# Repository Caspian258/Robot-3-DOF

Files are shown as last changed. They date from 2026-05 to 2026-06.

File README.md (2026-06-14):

# Robot 3-DOF

Sistema de control para un brazo robótico RRR de 3 grados de libertad, basado en ESP32 con control PD e interfaz gráfica en MATLAB.

## Inicio rápido

> **Requisito previo:** tener [Python 3.8+](https://www.python.org/downloads/) instalado.

**Linux / macOS**
```bash
bash tools/setup.sh
```

**Windows**
```
tools\setup.bat
```

El script instala PlatformIO y pyserial, y pre-descarga la plataforma ESP32 (~200 MB). Después solo necesitas conectar el ESP32 y ejecutar `cd firmware && pio run --target upload`.

---

## Requisitos

| Componente | Versión mínima | Notas |
|---|---|---|
| MATLAB | R2021a | `serialportlist()` requiere R2021a o superior |
| Python | 3.8+ | Solo para el bridge serial en Linux |
| PlatformIO CLI | cualquiera | Recomendado para flashear el firmware |
| Arduino IDE | 2.x | Alternativa a PlatformIO |

---

## Archivos del proyecto

| Archivo | Descripción |
|---|---|
| `firmware/robot3dof_firmware.ino` | Firmware para ESP32 — control PD de 3 motores DC con encoders |
| `firmware/platformio.ini` | Configuración de PlatformIO para ESP32 |
| `matlab/RobotController.m` | GUI de MATLAB — visualización 3D, cinemática inversa, telemetría en tiempo real |
| `tools/robot_serial_bridge.py` | Bridge serial en Python — evita conflictos de lock files en Linux |
| `tools/setup.sh` / `tools/setup.bat` | Scripts de instalación automática (Linux/macOS y Windows) |
| `requirements.txt` | Dependencias Python para el bridge |

---

## Hardware

- **Microcontrolador:** ESP32 DevKit
- **Motores:** 3× JGA25-370 DC con encoder magnético (6 cables)
- **Driver:** L298N (puente H por motor)

### Pines ESP32

| Motor | ENC_A | ENC_B | IN1 | IN2 | ENA |
|---|---|---|---|---|---|
| M1 (Base / yaw) | 18 | 19 | 21 | 22 | 23 |
| M2 (Hombro / pitch) | 32 | 33 | 25 | 26 | 27 |
| M3 (Codo / pitch) | 4 | 5 | 13 | 14 | 16 |

### Parámetros del robot

| Eslabón | Longitud |
|---|---|
| L1 (columna/base) | 100 mm |
| L2 (hombro) | 205 mm |
| L3 (codo/antebrazo) | 165.69 mm |

---

## Setup — Firmware ESP32

### Opción A: PlatformIO (recomendado)

El repositorio ya incluye `firmware/platformio.ini` configurado para la placa `esp32dev`.

1. Instalar Python 3.8+ si no lo tienes.
2. Instalar PlatformIO CLI:
   ```bash
   pip install platformio
   ```
3. Compilar y flashear:
   ```bash
   cd firmware
   pio run --target upload
   ```
   PlatformIO descarga automáticamente el toolchain de Espressif la primera vez.

4. Monitor serial (opcional):
   ```bash
   pio device monitor --baud 115200
   ```

### Opción B: Arduino IDE 2.x

1. Descargar e instalar [Arduino IDE 2.x](https://www.arduino.cc/en/software).
2. Abrir **File → Preferences** y agregar esta URL en "Additional boards manager URLs":
   ```
   https://raw.githubusercontent.com/espressif/arduino-esp32/gh-pages/package_esp32_index.json
   ```
3. Ir a **Tools → Board → Boards Manager**, buscar `esp32` e instalar el paquete de Espressif.
4. Seleccionar **Tools → Board → ESP32 Arduino → ESP32 Dev Module**.
5. Abrir `firmware/robot3dof_firmware.ino`, compilar y subir.

> El firmware no requiere librerías externas — solo el core Arduino para ESP32.

---

## Setup — GUI MATLAB

**Requisito:** MATLAB R2021a o superior (sin toolboxes adicionales).

1. Conectar el ESP32 por USB.
2. Abrir MATLAB, navegar a la carpeta `matlab/` y ejecutar:
   ```matlab
   RobotController
   ```
3. Seleccionar el puerto serial en el desplegable (ej. `COM3` en Windows, `/dev/ttyUSB0` en Linux).
4. Presionar **CONECTAR**.
5. Introducir coordenadas X, Y, Z en mm y presionar **EJECUTAR TRAYECTORIA**.

---

## Setup — Bridge Python (solo Linux, opcional)

Útil cuando MATLAB no puede adquirir el lock del puerto serial en Linux.

```bash
pip install -r requirements.txt
python tools/robot_serial_bridge.py
```

---

## Protocolo Serial (115200 baud)

### MATLAB → ESP32

| Comando | Descripción |
|---|---|
| `T,deg1,deg2,deg3` | Nuevo setpoint en grados para los 3 motores |
| `K1,Kp,Kd` | Ganancias PD del motor 1 |
| `K2,Kp,Kd` | Ganancias PD del motor 2 |
| `K3,Kp,Kd` | Ganancias PD del motor 3 |
| `DB,d1,d2,d3` | Zona muerta por motor (grados) |
| `ZERO` | Resetear encoders y setpoints a cero |
| `DISARM` | Desactivar control, motores en freno |
| `FREE` | Soltar corriente (motores libres) |

### ESP32 → MATLAB

| Respuesta | Descripción |
|---|---|
| `D,q1,q2,q3,e1,e2,e3,pwm1,pwm2,pwm3` | Telemetría: posición actual, error y PWM de los 3 motores |
| `READY` | ESP32 listo tras el boot |
| `ZEROED` | Confirmación de reset de encoders |
| `DISARMED` | Confirmación de desactivación |
| `FREE` | Confirmación de motores libres |

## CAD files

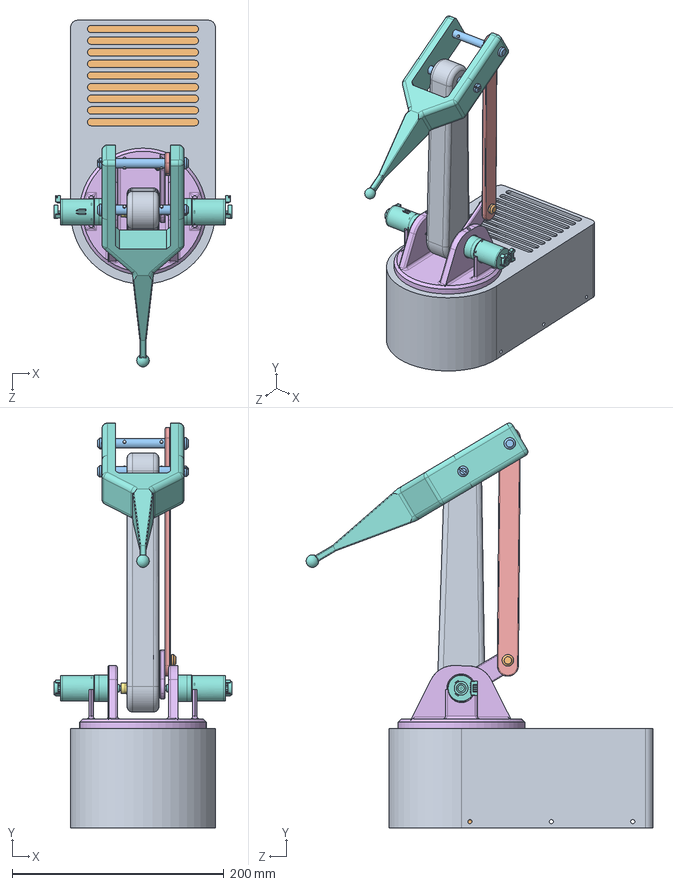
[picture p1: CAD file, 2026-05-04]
CAD/3DOFROBOT.SLDASM
167.8 x 382.8 x 327.8 mm
Arm1
Arm2
PIN3
Base
RotatoryBase
GearBaseRod
GearBaseServo
BoxBase
BoxTop
GM25-370 x 3
5mmFlangeCoupler x 2
ESLABON 2
ESLABON
BALERO
EJE LARGO x 2
Eje corto
Segurito x 4

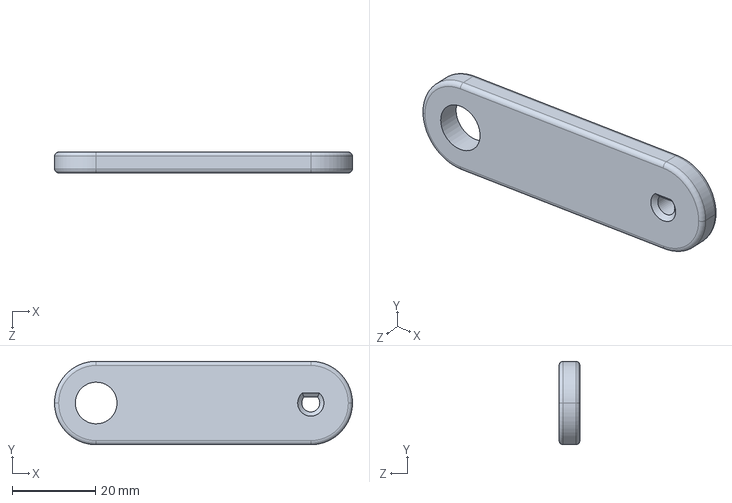
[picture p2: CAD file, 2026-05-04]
CAD/ESLABON 2.SLDPRT
71.5 x 20.0 x 5.00 mm

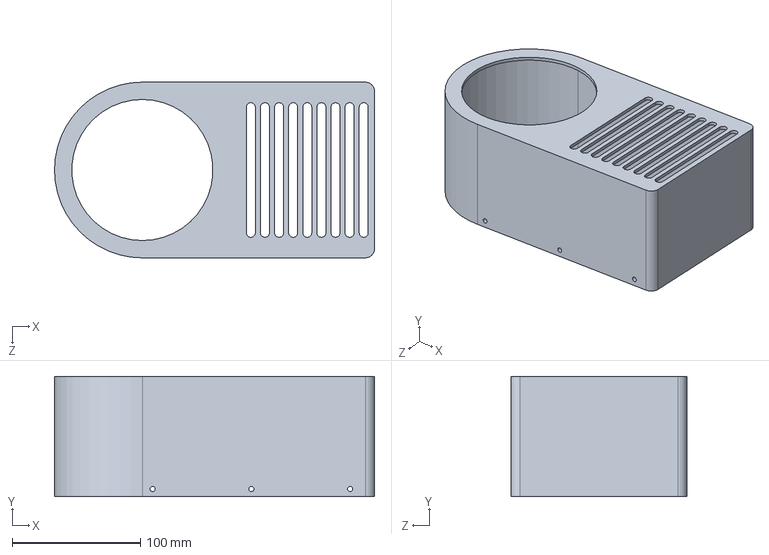
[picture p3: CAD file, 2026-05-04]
CAD/BoxTop.SLDPRT
249.5 x 93.9 x 137.0 mm

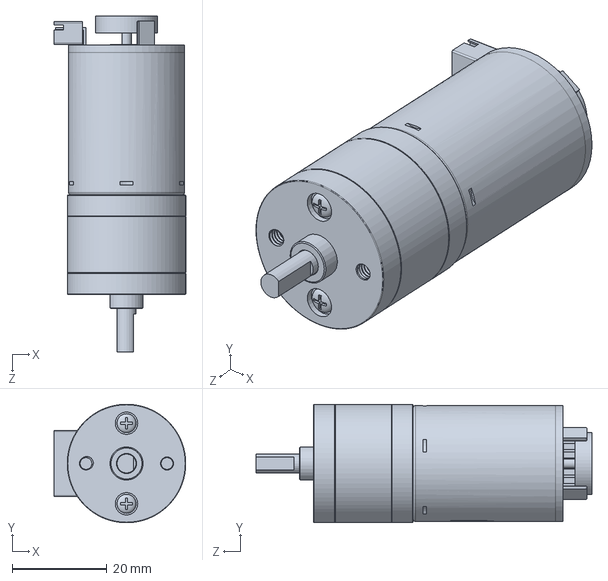
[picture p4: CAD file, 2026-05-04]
CAD/GM25-370.SLDPRT
27.8 x 25.0 x 70.9 mm

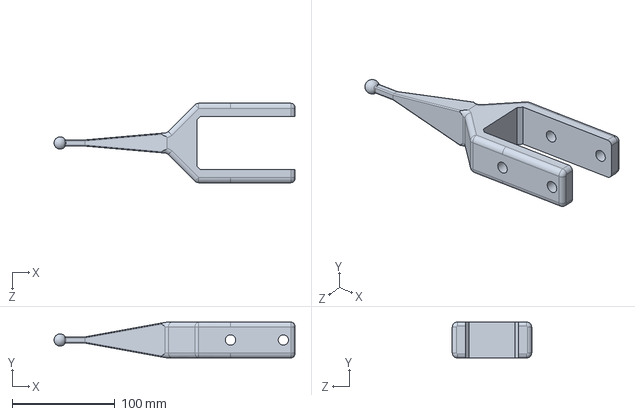
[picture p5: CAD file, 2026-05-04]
CAD/Arm2.SLDPRT
234.5 x 35.0 x 77.4 mm

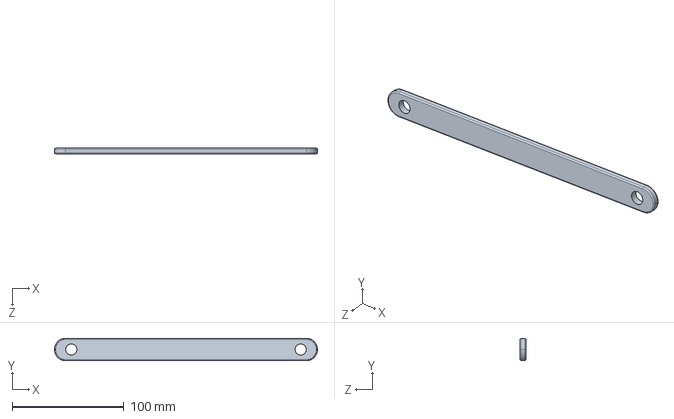
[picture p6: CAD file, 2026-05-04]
CAD/ESLABON.SLDPRT
235.0 x 20.0 x 5.00 mm

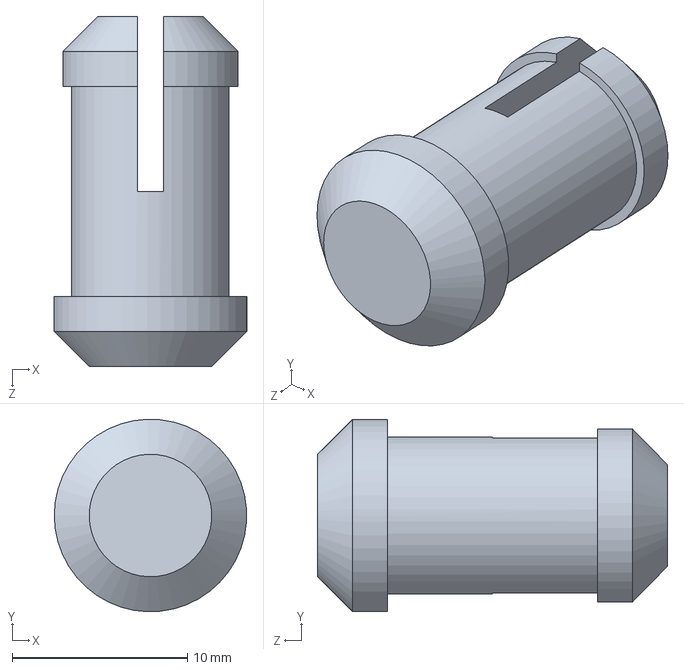
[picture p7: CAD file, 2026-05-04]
CAD/Eje corto.SLDPRT
11.0 x 11.0 x 20.0 mm

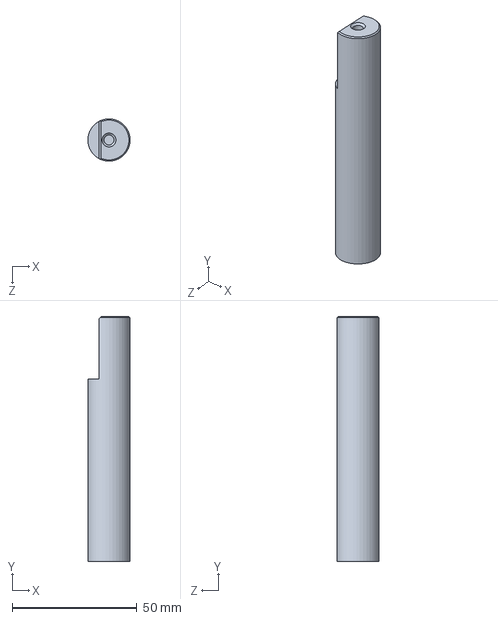
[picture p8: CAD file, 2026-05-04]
CAD/PIN3.SLDPRT
16.9 x 98.3 x 17.0 mm

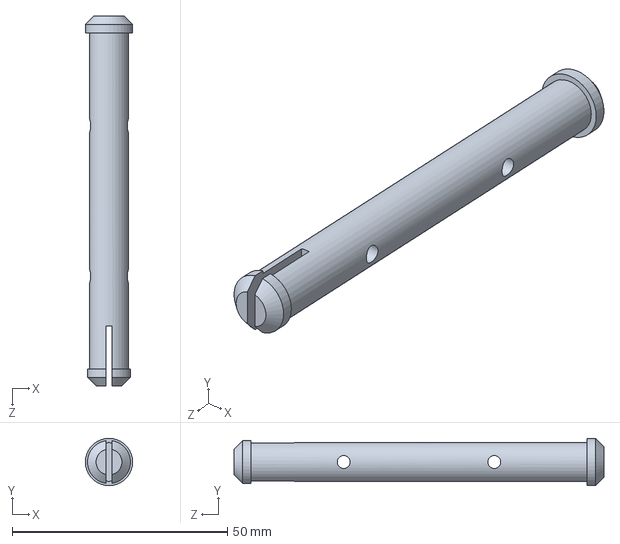
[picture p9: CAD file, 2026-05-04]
CAD/EJE LARGO.SLDPRT
11.0 x 11.0 x 86.0 mm

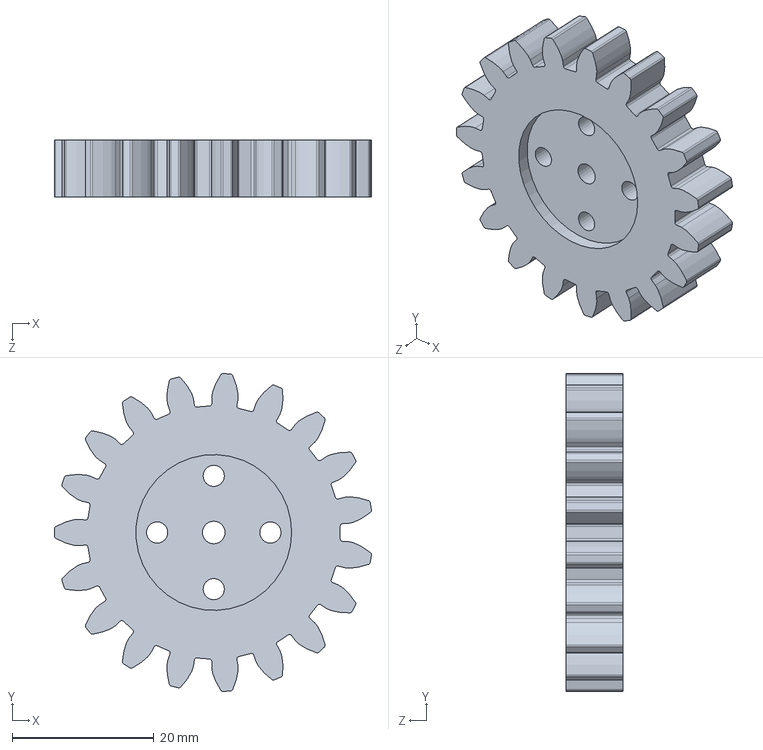
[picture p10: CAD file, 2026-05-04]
CAD/GearBaseServo.SLDPRT
44.8 x 44.9 x 8.00 mm

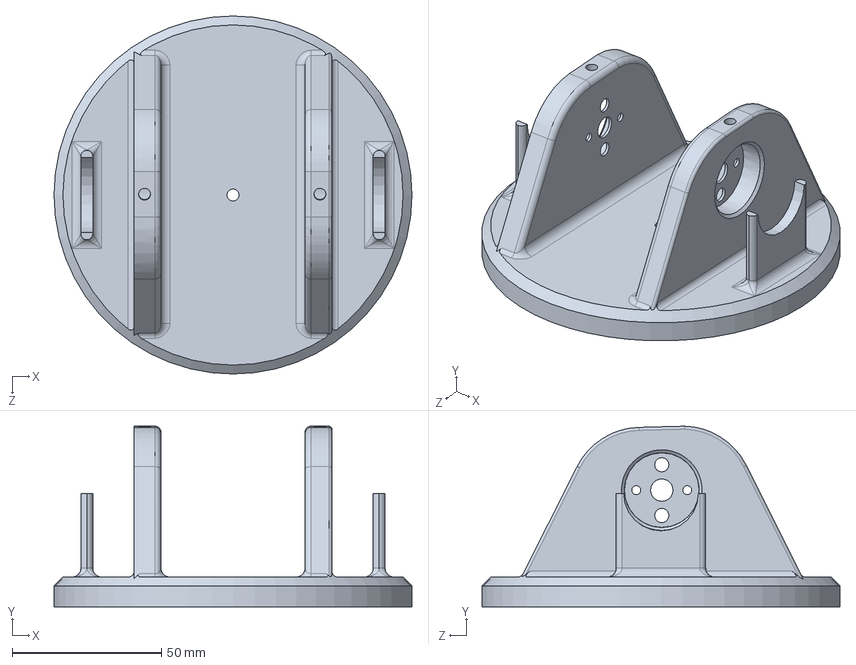
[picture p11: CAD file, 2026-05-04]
CAD/Base.SLDPRT
120.0 x 60.6 x 120.0 mm

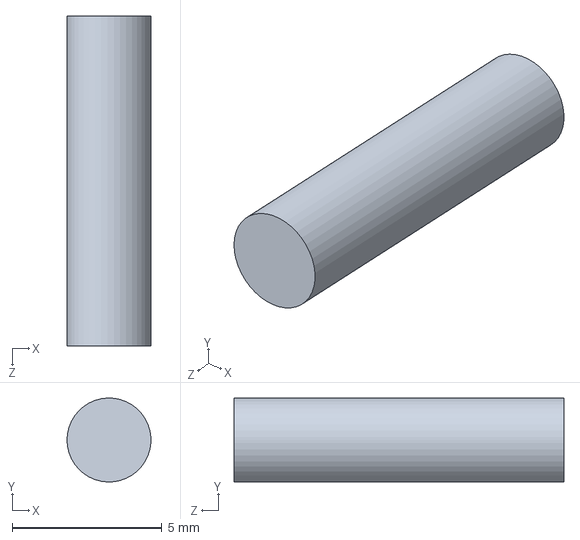
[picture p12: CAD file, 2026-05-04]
CAD/Segurito.SLDPRT
2.80 x 2.80 x 11.0 mm

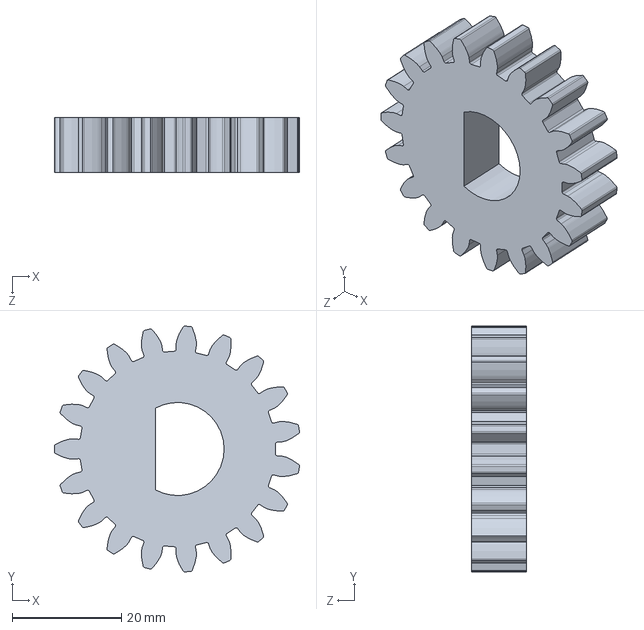
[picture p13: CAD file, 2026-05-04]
CAD/GearBaseRod.SLDPRT
44.8 x 44.9 x 10.0 mm

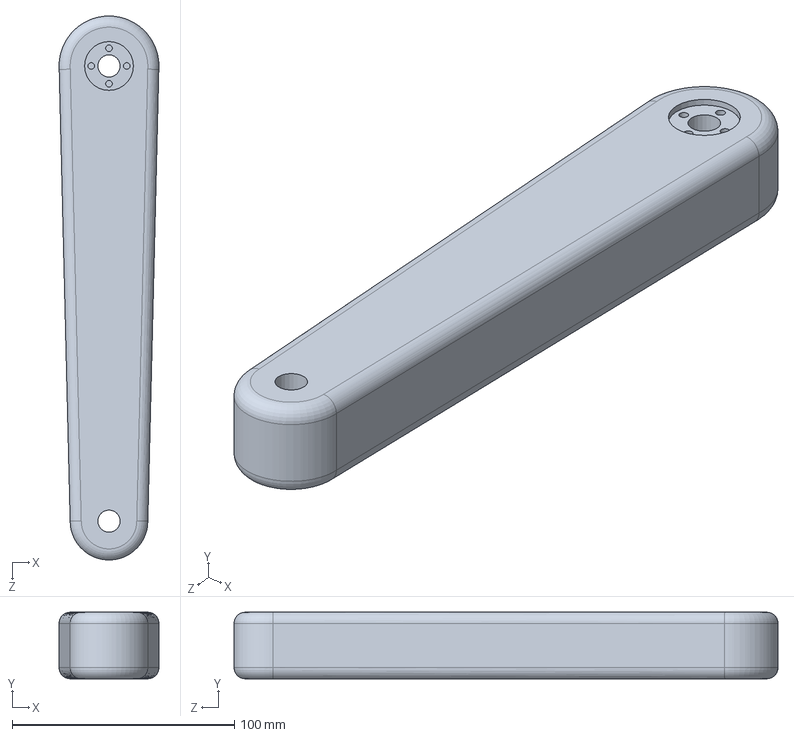
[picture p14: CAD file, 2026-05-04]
CAD/Arm1.SLDPRT
45.0 x 30.0 x 245.0 mm

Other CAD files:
CAD/BoxBase.SLDPRT
CAD/5mmFlangeCoupler.SLDPRT
CAD/BALERO.SLDPRT
CAD/RotatoryBase.SLDPRT

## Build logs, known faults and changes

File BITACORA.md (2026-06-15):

# BITACORA.md — Robot RRR 3-DOF

Registro de avances por sesión de trabajo. Orden cronológico descendente (más reciente arriba).

---

## 2026-06-14 — MIN_PWM y kickstart independientes por motor + fix script

### Qué se hizo y por qué

Mediciones físicas confirmaron que cada articulación tiene fricción estática diferente:
- M1 (base, reducción 70:1 + masa del brazo completo): fricción muy alta
- M2 (hombro, levanta el antebrazo): fricción media
- M3 (codo, carga menor): fricción baja, ya funcionaba bien

**Cambio firmware — arrays por motor (reemplaza escalares globales):**

| Parámetro | M1 (Base) | M2 (Hombro) | M3 (Codo) | Anterior (global) |
|---|---|---|---|---|
| `MIN_PWM_CERCA` (error < 6°) | 100 | 75 | 60 | 60 |
| `MIN_PWM_LEJOS` (error ≥ 6°) | 130 | 100 | 80 | 80 |
| `KICK_PWM` | 180 | 140 | 120 | 120 |
| `KICK_MS` (duración) | 120 ms | 80 ms | 80 ms | 80 ms |

Nota: `KICK_PWM[0]=180 > 150` (umbral anti-atasco), pero el kick dura solo 120 ms
(≈12 ciclos a 100 Hz), insuficiente para alcanzar los 50 ciclos necesarios para
disparar FAULT. Tras el kick, `MIN_PWM_LEJOS[0]=130 < 150` → anti-atasco en reposo.

**Fix script — falsos positivos de LIMIT en paso 6:**

`_printed_limits = set()` → `_printed_limits = set(self.limits_hit)` en
`esperar_posicion()`. Ahora solo se reportan mensajes LIMIT NUEVOS en cada llamada;
los acumulados de paso 4 no se re-imprimen en paso 6.

### Estado actual

| Componente | Estado |
|---|---|
| Firmware per-motor | ✅ Compila [SUCCESS] 21.6% Flash, 6.8% RAM |
| Upload al ESP32 | ⏳ Pendiente confirmación del usuario |
| Script Fix 6 | ✅ Corregido — no más falsos LIMIT:M3 en paso 6 |

### Próximos pasos

1. **Subir firmware** y correr `verificacion_sistema.py`
2. **Si M1 sigue sin arrancar**: subir `KICK_PWM[0]` hasta 210, vigilar que
   FAULT no se dispare (stall_cnt acumula durante kick pero no llega a 50)
3. **Si M2/M3 muestran overshoot excesivo**: bajar `KICK_PWM` de ese motor

---

## 2026-06-14 — Kickstart anti-fricción y ajuste de parámetros PD

### Qué se hizo y por qué

Confirmado físicamente: los 3 motores tienen fricción estática alta que impide arrancar desde reposo con parámetros anteriores. Después de descartar causas de software (código simétrico, ZERO limpia todo el estado), la evidencia apunta al hardware: los motores JGA25-370 con su reducción 70:1 tienen fricción estática significativa que requiere un burst de potencia inicial para vencer.

**Cambio 1 — MIN_PWM 30/55 → 60/80:**
- Zona cercana (error < 6°): 30 → 60
- Zona lejana (error > 6°): 55 → 80
- Garantiza torque mínimo suficiente en todo momento, incluso en dirección positiva (contra gravedad)

**Cambio 2 — Kickstart anti-fricción (`kick_ms[3]`, `PWM_KICK=120`):**
- Al recibir nuevo comando T o al salir de HOLDING por perturbación: `kick_ms[i] = 80` ms
- Durante esos 80 ms: `power = max(power, 120)` — override del PD calculado
- Después de 80 ms: retoma control PD normal con parámetros actuales
- Resetea en ZERO, DISARM y T handler
- PWM_KICK = 120 < umbral de anti-atasco (150) → no dispara FAULT

**Cambio 3 — Kp 6→8, Kd 0.08→0.10:**
- Kp más alto: más fuerza proporcional en rango medio (antes: 6×10°=60, ahora: 8×10°=80 PWM)
- Kd más alto: más amortiguación para compensar el mayor Kp y evitar overshoot

### Parámetros antes y después

| Parámetro | Antes | Después |
|---|---|---|
| `Kp` | 6.0 | 8.0 |
| `Kd` | 0.08 | 0.10 |
| `min_pwm` (zona cercana, error < 6°) | 30 | 60 |
| `min_pwm` (zona lejana, error > 6°) | 55 | 80 |
| Kickstart | — | 120 PWM × 80 ms al arrancar |

### Estado actual

| Componente | Estado |
|---|---|
| Firmware kickstart | ✅ Compila [SUCCESS] 21.6% Flash, 6.8% RAM |
| Upload al ESP32 | ⏳ Pendiente confirmación del usuario |

### Próximos pasos

1. **Subir firmware** y correr `verificacion_sistema.py` para medir mejora
2. **Si overshoot > 10°**: bajar Kp de 8 a 7
3. **Si sigue sin arrancar en positivo**: subir PWM_KICK de 120 a 150 (máximo antes de stall)
4. **Fix pendiente en script**: Fix 6 introduce falsos positivos de LIMIT — inicializar `_printed_limits = set(self.limits_hit)` en vez de `set()`

---

## 2026-06-14 — Corrección asimetría PD y script de verificación

### Qué se hizo y por qué

**Diagnóstico (verificacion_sistema.py con robot físico):**

| Motor | Dirección | Pedido | Llegó | Error SS |
|---|---|---|---|---|
| M1 | positivo | +10° | 4.8° | -5.2° |
| M1 | positivo | +25° | 15.1° | -9.9° |
| M1 | negativo | -10° | -8.8° | +1.2° |
| M2 | positivo | +10° | 3.5° | -6.5° |
| M3 | positivo | +10° | 7.0° | -3.0° |

Patrón: todos los motores se quedan cortos en positivo, negativos funcionan mejor.

**Análisis de causa raíz (dos agentes en paralelo):**

El código de control es 100% simétrico (L223, L256, L259, L284, L175 del firmware).
La asimetría es física: la carga gravitacional requiere más torque en dirección positiva
(contra gravedad). Con Kp=6, a ~5° del target el término proporcional = 31 PWM, y
`min_pwm = 20` (error < 3×deadband = 6°) → motor no vence la fricción estática. En
negativo, la gravedad asiste y 31 PWM es suficiente.

**Fix 1 — Firmware: `min_pwm` 20/35 → 30/55 (L259 firmware):**

Garantiza torque mínimo suficiente en ambas direcciones, independiente del Kp.
El término 30 aplica cerca del target (error < 6°) y 55 fuera de esa zona.
No cambia la dinámica de control, solo el piso de esfuerzo.

**Fix 2 — Script: lista de pruebas de límites incompleta:**

La lista `pruebas` en `paso4_limites_software` solo cubría 4 de los 6 casos.
Añadidos M2 negativo (−50° → −45°) y M3 negativo (−50° → −45°).

**Fix 3 — Script: timeout adaptativo:**

`timeout_adap = 4.0 if abs(angulo_fw) <= 15 else 8.0` — evita falsas alarmas de
timeout en movimientos pequeños y da tiempo suficiente a los grandes.

**Fix 4 — Script: retorno a cero más estricto:**

`db=5.0° → db=2.0°` en el retorno entre pruebas — garantiza que cada prueba
parte de 0° ± 2° (= deadband) en lugar de 0° ± 5°.

**Fix 5 — Script: reemplazar sleep(1.5) en paso4:**

`time.sleep(1.5) → robot.esperar_posicion([0,0,0], db=3.0, timeout=4.0)` —
verifica posición real en vez de esperar a ciegas.

**Fix 6 — Script: log de LIMIT: durante movimiento:**

`esperar_posicion()` ahora imprime cada mensaje LIMIT: nuevo que recibe durante
el movimiento, con color amarillo.

### Estado actual

| Componente | Estado |
|---|---|
| Firmware min_pwm | ✅ 30/55 — compila [SUCCESS] 21.6% Flash, 6.8% RAM |
| Script límites | ✅ 6 casos (±M1/M2/M3) |
| Script timeout | ✅ Adaptativo: 4s ≤15°, 8s >15° |
| Script retorno cero | ✅ db=2° (era 5°) |

### Próximos pasos

1. **Subir firmware** (`cd firmware && pio run --target upload`) — pendiente confirmación
2. **Ejecutar verificacion_sistema.py** nuevamente para confirmar que la asimetría se reduce
3. **Si persiste el undershoot**: aumentar Kp de 6→8 para aumentar torque proporcional

---

## 2026-06-14 — Rediseño GUI en 3 columnas

### Qué se hizo y por qué

Layout anterior (2 columnas internas dentro de un panel de 390px) dejaba solo ~192px por columna → textos cortados, botones demasiado pequeños.

Solución: **3 columnas independientes en `mainGrid`**:

| Columna | Ancho | Contenido |
|---|---|---|
| C1 (pnlC1 / g1) | 280 px fijo | DESTINO · SECUENCIA · GANANCIAS PD · ZONA MUERTA |
| C2 (pnlC2 / g2) | 280 px fijo | CONTROL MANUAL · TEST MOTORES · CONEXIÓN · CERO · FK · LOG |
| C3 | 1x (resto) | Modelo 3D + gráfica de control |

Cambios adicionales:
- `RowHeight` de mainGrid: `{'1x', 260}` (panel inferior ligeramente más bajo que antes para dar más espacio al 3D)
- Valores por defecto de Kp/Kd corregidos a **6.0/0.08** (firmware actual; antes mostraban 10.0/0.05)
- Deadband default: 2.0° (ya correcto desde sesión anterior)
- `FontSize` uniformado a 11-13 en todos los controles para legibilidad completa
- Labels descriptivos en CERO y SOLTAR CORRIENTE explican la acción al usuario

### Estado actual

| Componente | Estado |
|---|---|
| Layout GUI | ✅ 3 columnas — 280+280+resto — todos los textos completos sin corte |
| Ganancias por defecto | ✅ Kp=6.0 / Kd=0.08 (coherentes con firmware) |
| Callbacks | ✅ Todos los nombres de variables preservados sin cambios |

### Próximos pasos

1. **Ejecutar verificacion_sistema.py** con robot físico conectado
2. **Subir firmware** con nuevos parámetros PD (`cd firmware && pio run --target upload`)
3. **Verificar animación 3D** — en posición cero el brazo debe mostrar la "L invertida"

---

## 2026-06-14 — Panel izquierdo dos columnas + script de verificación completa

### Qué se hizo y por qué

**Problema 1 — Fix definitivo del scroll del panel izquierdo:**

El `uipanel` con `Scrollable='on'` dentro de un `uigridlayout` no genera scroll en MATLAB/Linux: el grid layout toma control del tamaño del panel y clipa el contenido sin desplazarlo (bug de interacción entre uipanel scrollable y uigridlayout como padre).

Solución: panel izquierdo dividido en **dos columnas** con `uigridlayout [1,2]` sin scroll:
- Columna L (16 filas, ~504px): DESTINO · SECUENCIA · GANANCIAS PD · ZONA MUERTA
- Columna R (20 filas, ~724px): CONTROL MANUAL · TEST MOTORES · CONEXIÓN · CERO · FK · LOG
- Ambas columnas caben en los ~968px disponibles sin necesitar scroll.

**Problema 2 — Script de verificación completa `tools/verificacion_sistema.py`:**

Diagnóstico de 7 pasos ejecutable sin MATLAB. Uso: `python3 tools/verificacion_sistema.py /dev/ttyUSB0`

| Paso | Qué verifica |
|---|---|
| 1 | Comunicación serial (20 tramas, frecuencia real, formato D,) |
| 2 | Estabilidad de encoders en reposo (deriva < 1°, ruido por trama) |
| 3 | Respuesta por motor: 10°/25°/-10°/-25°/0° con tabla de tiempo de respuesta, error SS y overshoot |
| 4 | Límites por software (enviar > 80°/45° → verificar LIMIT:Mn) |
| 5 | Revisión estática del código anti-atasco en firmware (sin prueba física) |
| 6 | Movimiento combinado 3 motores: T,20,20,20 → T,-20,-20,-20 → ZERO |
| 7 | Semáforo 🟢/🟡/🔴 con recomendaciones de ajuste PD |

Seguridad: DISARM inmediato si FAULT o error > 30° por > 3s. Siempre termina con ZERO.

### Estado actual

| Componente | Estado |
|---|---|
| Panel izquierdo GUI | ✅ Dos columnas — todo el contenido visible sin scroll |
| Script verificacion_sistema.py | ✅ Listo — pendiente ejecutar con robot físico |

### Próximos pasos

1. **Ejecutar verificacion_sistema.py** con robot físico conectado y confirmar pasos 1-7
2. **Verificar animación 3D** — en posición cero el brazo debe mostrar la "L invertida"
3. **Subir firmware** con nuevos parámetros PD (`pio run --target upload`)

---

## 2026-06-14 — Revisión control PD, corrección visual M2/M3 y mejoras GUI

### Qué se hizo y por qué

**Fase 2A — MATLAB (`matlab/RobotController.m`):**

| Cambio | Motivo |
|---|---|
| Negar `current_q(2/3)` antes de sumar `home_q` en `leerTelemetria()` y `leerUnFrame()` | La convención del encoder de M2/M3 es opuesta a la cinemática: el encoder lee negativo cuando el motor va físicamente positivo (corrección INVERTIDO es eléctrica, no invierte ISR) |
| Negar `q_fw(2/3)` en `moverRobot()` antes de enviar `T,` | Para que IK→firmware sea coherente con la misma convención |
| Negar `fw_target1/2(2/3)` en `runSequence()` | Para que `esperarPosicionMulti()` compare contra el valor de encoder que el firmware realmente alcanzará |
| Parsear `FAULT:` y `LIMIT:` en `leerTelemetria()` y mostrar en LOG | Antes se descartaban silenciosamente; ahora aparecen como `[!] FAULT:M1 — motor bloqueado` |
| Buffer CSV: acumular 50 tramas antes de escribir a disco | Elimina `fopen/fclose` 100×/s → reduce carga de I/O |

**Fase 2B — Firmware (`firmware/robot3dof_firmware.ino`):**

| Cambio | Valor anterior | Valor nuevo | Motivo |
|---|---|---|---|
| Kp | 10.0 | 6.0 | Reduce overshoot con errores grandes (Kp=10 → PWM saturado a 255 inmediato) |
| Kd | 0.05 | 0.08 | Mayor amortiguación para compensar Kp reducido |
| Filtro derivativo | sin filtro | α=0.7 (`d_f = 0.7*d_prev + 0.3*d_raw`) | Elimina picos derivativos al cambiar setpoint bruscamente |
| Rate limiter | sin rate limit | 1°/ciclo si salto >30° | Previene saturación de PWM al inicio de movimientos grandes; arranca desde `current_q` |

El rate limiter cancela el estado `holding` mientras la rampa avanza, para que el motor siga activamente la rampa sin necesitar esperar a superar `1.5×deadband`.

### Estado actual

| Componente | Estado |
|---|---|
| Animación 3D M2/M3 | ✅ Corregida — convención de encoder M2/M3 compensada en visualización |
| IK→firmware M2/M3 | ✅ Corregido — setpoints negados para encoder invertido |
| FAULT/LIMIT en GUI | ✅ Visibles en LOG de la GUI |
| CSV buffering | ✅ Escribe cada 50 tramas en vez de cada frame |
| Control PD | ✅ Kp=6 / Kd=0.08 / filtro derivativo α=0.7 / rate limiter 1°/ciclo |

### Próximos pasos

1. **Verificar con robot físico** — enviar T,0,20,0 y confirmar que M2 va a +20° físicos
2. **Tuning fino** si Kp=6 resulta muy lento: considerar subir a 7-8 para M1 (más inercia)
3. **Verificar animación** — en posición cero el brazo debe mostrar la "L invertida" (home=[0,90,-90])

---

## 2026-06-14 — Diagnóstico completo + protección anti-atasco + control por teclado

### Qué se hizo y por qué

**Diagnóstico físico con `tools/diagnostico_movimiento.py`:**

Hallazgos críticos encontrados al correr la secuencia de pruebas:

| Motor | Resultado | Causa |
|---|---|---|
| M1 (Base) | Converge lentamente (~85-90% en 4s) | Kp=10 bajo para la inercia del sistema |
| M2 (Hombro) | **Dirección INVERTIDA** — corrió a -49.6° al pedir +10° | Wiring: encoder/motor en convención opuesta |
| M3 (Codo) | **Dirección INVERTIDA + atasco** — PWM=255 en posición incorrecta | Igual que M2, chocó contra tope mecánico |

**Fase 3 — Firmware (`firmware/robot3dof_firmware.ino`):**
- `INVERTIDO[3] = {false, true, true}`: corrige dirección de M2 y M3 via XOR en la lógica de dirección (sin tocar hardware ni ISRs)
- Límites por software `LIMIT_NEG/LIMIT_POS`: clampea setpoints a ±80°/±45°/±45°, responde `LIMIT:M{n}` si se supera
- Anti-atasco: PWM>150 y encoder quieto (<5 counts) durante 500ms → `FAULT:M{n}`, motor apagado hasta ZERO o DISARM
- Deadband reducida de 5° a 2° (commit anterior): ángulo mínimo funcional ~3°
- GUI default de deadband actualizado de 5° a 2° para consistencia

**Fase 4 — MATLAB (`matlab/RobotController.m`):**
- Panel "CONTROL MANUAL (teclado)" en la GUI
- `fig.KeyPressFcn` → `teclasRobot()`: A/D=M1, W/S=M2, Q/E=M3 (±5°/tecla), Espacio=DISARM, R=ZERO
- Respeta límites ±80°/±45°/±45° antes de enviar comando
- Loguea cada acción en el panel LOG

### Estado actual

| Componente | Estado |
|---|---|
| M1 (Base) | ✅ Dirección correcta — converge, algo lento |
| M2 (Hombro) | ✅ Dirección corregida por software (INVERTIDO[1]=true) |
| M3 (Codo) | ✅ Dirección corregida por software (INVERTIDO[2]=true) |
| Anti-atasco | ✅ Implementado — FAULT:M{n} si 500ms sin movimiento con PWM>150 |
| Límites software | ✅ Implementados — LIMIT:M{n} si setpoint supera topes |
| Control teclado | ✅ A/D/W/S/Q/E + Espacio + R en la GUI MATLAB |
| PULSOS_POR_VUELTA | ⚠️ 1960 (teórico) — pendiente verificación M1 con nueva dirección de M2/M3 |

### Próximos pasos

1. **Verificar M2 y M3** con la nueva dirección — enviar T,0,20,0 y T,0,0,20
2. **Tuning Kp M1** — considerar subir de 10 a 15-20 si sigue convergiendo lento
3. **Verificar PULSOS_POR_VUELTA** — confirmar 1 vuelta exacta en los 3 motores
4. **Probar control por teclado** con robot físico conectado

---

## 2026-06-14 — Corrección de PULSOS_POR_VUELTA (verificación física)

### Qué se hizo y por qué

Corregida la constante `PULSOS_POR_VUELTA` en `firmware/robot3dof_firmware.ino` de **1200** a **1960**.

- **Evidencia física:** con el valor 1200, al enviar `T,360,0,0` el motor M1 giraba solo ~220° en lugar de 360°.
- **Cálculo teórico:** JGA25-370 con encoder de 6 cables (~7 PPR) × 4× (decodificación de cuadratura) × reducción 70:1 ≈ **1960 counts/rev**.
- Actualizados `CLAUDE.md` (parámetros de control y nota de verificación) para reflejar el valor correcto.

### Estado actual

| Componente | Estado |
|---|---|
| `PULSOS_POR_VUELTA` | ✅ Corregido a 1960 (verificación física M1) |

### Próximos pasos

1. **Verificar en físico** — con el nuevo valor enviar `T,360,0,0` y confirmar 1 vuelta exacta
2. **Probar robot_serial_bridge.py** en Linux como alternativa permanente al lock file
3. **Conectar M2 y M3** — verificar dirección de giro y pines

---

## 2026-06-14 — Reorganización de estructura de carpetas

### Qué se hizo y por qué

Reorganización del repositorio para separar responsabilidades por directorio:

| Movimiento | Origen → Destino |
|---|---|
| Firmware | `robot3dof_firmware.ino`, `platformio.ini` → `firmware/` |
| GUI MATLAB | `RobotController.m` → `matlab/` |
| Herramientas | `robot_serial_bridge.py`, `setup.sh`, `setup.bat` → `tools/` |
| Docs | `docs/` creada (vacía con `.gitkeep`) |

Todos los movimientos se hicieron con `git mv` para preservar el historial de cada archivo.
Compilación verificada: `cd firmware && pio run` → `[SUCCESS]` 21.5% Flash, 6.8% RAM.
README.md, CLAUDE.md y BITACORA.md actualizados con las nuevas rutas.

### Estado actual

Igual que sesión anterior — solo cambió la estructura de carpetas, no el código.

### Próximos pasos

1. **Verificar PULSOS_POR_VUELTA** — conectar M1, enviar `T,360,0,0`, confirmar 1 vuelta exacta
2. **Probar `tools/robot_serial_bridge.py`** en Linux como alternativa al lock file de MATLAB
3. **Conectar M2 y M3** — verificar dirección de giro y pines con testMotores()
4. **Tuning PD** — ajustar Kp/Kd y deadband por motor con el robot físico

---

## 2026-06-14 — Auditoría, limpieza de repo y correcciones técnicas

### Qué se hizo y por qué

**Diagnóstico de conexión MATLAB↔ESP32 (Linux):**
- Causa identificada: `/run/lock` tiene permisos `0755 root:root` — MATLAB no puede crear lock files
- Python/pyserial sí funciona (no usa lock files). El ESP32 responde correctamente tramas `D,`
- Fix temporal: `sudo chmod 1777 /run/lock`
- Fix permanente: crear `robot_serial_bridge.py` (pendiente) y configurar tmpfiles.d

**Auditoría completa del proyecto:**
- Protocolo serial: 100% sincronizado entre firmware y GUI (T,/D, es el protocolo real)
- Pines: verificados — los tres archivos (firmware, CLAUDE.md, README) coinciden
- Inconsistencia crítica encontrada: `PULSOS_POR_VUELTA` en firmware = 1200, docs = 994
- `.vscode/` y 255 archivos de proyecto anterior estaban tracked en git

**Limpieza del repo (commit a66c6a9):**
- Eliminados del índice: `Implementacion ROS/` (proyecto ROS2 distinto) y `Validaciones numericas/`
- Untrackeado: `.vscode/` (auto-generado por PlatformIO; ya estaba en .gitignore)
- `git status` queda limpio

**Actualización CLAUDE.md (commit b4cd67a):**
- Protocolo corregido: eliminados SP:/POS:/RST/KP:/KD: (no existen en firmware)
- Parámetros reales: Kp=10.0, Kd=0.05, min_pwm=20/35, LOOP_HZ=~100
- COUNTS/REV marcado como pendiente de verificación física (firmware=1200, docs=994)
- Cinemática: agregado θ3_motor = θ2 + θ3_rel - π/2 y advertencia de workspace
- Estructura del repo actualizada al estado real

**Correcciones técnicas aplicadas:**
- ISR race condition: protegido `encCount` con `portMUX_TYPE` en firmware
- `platformio.ini`: agregado `monitor_filters = esp32_exception_decoder`
- GUI MATLAB: agregado botón "Refresh ports" en dropdown serial
- GUI MATLAB: agregada validación de workspace en `ikRobot()` con advertencia al usuario
- Creado `robot_serial_bridge.py`: bridge Python para evitar lock file de MATLAB en Linux

### Estado actual

| Componente | Estado |
|---|---|
| Firmware ESP32 | ✅ Compila y flashea. Control PD + HOLDING funcional |
| GUI MATLAB | ✅ Funcional con mejoras (refresh ports, validación IK) |
| Comunicación serial | ✅ Verificada con Python — ESP32 responde correctamente |
| M1 (Base) | ✅ Conectado físicamente |
| M2 (Hombro) | ⚠️ Cableado sin verificar en movimiento |
| M3 (Codo) | ⚠️ Cableado sin verificar en movimiento |
| PULSOS_POR_VUELTA | ⚠️ Firmware usa 1200, pendiente verificación física |
| Lock file Linux | ⚠️ Requiere `sudo chmod 1777 /run/lock` o robot_serial_bridge.py |

### Próximos pasos

1. **Verificar PULSOS_POR_VUELTA** — conectar M1, enviar `T,360,0,0`, confirmar 1 vuelta exacta
2. **Probar robot_serial_bridge.py** en Linux como alternativa permanente al lock file
3. **Conectar M2 y M3** — verificar dirección de giro y pines con testMotores()
4. **Tuning PD** — ajustar Kp/Kd y deadband por motor con el robot físico
5. **Validación de workspace** — probar con coordenadas reales del reto escolar

---

## Sesiones anteriores

*(Registro no disponible — esta bitácora se inicia el 2026-06-14)*

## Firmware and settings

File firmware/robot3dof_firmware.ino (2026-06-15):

#include <Arduino.h>

// =============================================================
//  Robot RRR 3DOF - Firmware ESP32
//  Control PD con estado HOLDING: al estabilizarse corta energía
//  y no vuelve a escribir pines hasta recibir nuevo target.
// =============================================================

// --- PINES DE POTENCIA ---
// Bloques consecutivos sin conflicto con encoders ni pines input-only
const int M1_IN1 = 21; const int M1_IN2 = 22; const int M1_ENA = 23;
const int M2_IN1 = 25; const int M2_IN2 = 26; const int M2_ENA = 27;
const int M3_IN1 = 13; const int M3_IN2 = 14; const int M3_ENA = 16;

// --- PINES DE ENCODERS (verificados físicamente) ---
const int M1_ENCA = 18; const int M1_ENCB = 19;
const int M2_ENCA = 32; const int M2_ENCB = 33;
const int M3_ENCA = 4;  const int M3_ENCB = 5;

// --- CONSTANTES ---
const float PULSOS_POR_VUELTA = 1960.0f;

// Sentido de giro físico por motor respecto a la convención del encoder.
// true = invertido (verificado 2026-06-14: M2 y M3 van en negativo al pedir positivo).
const bool INVERTIDO[3] = {false, true, true};

// Límites por software — segunda defensa tras los topes mecánicos físicos.
const float LIMIT_NEG[3] = {-80.0f, -45.0f, -45.0f};
const float LIMIT_POS[3] = { 80.0f,  45.0f,  45.0f};

// --- TARGETS Y POSICIÓN ---
float target_q[3]  = {0.0f, 0.0f, 0.0f};
float current_q[3] = {0.0f, 0.0f, 0.0f};

// --- GANANCIAS PD ---
float Kp[3] = {8.0f, 8.0f, 8.0f};
float Kd[3] = {0.10f, 0.10f, 0.10f};

// --- ZONA MUERTA (grados) — reducida de 5° a 2° para responder a ángulos pequeños ---
float deadband[3] = {2.0f, 2.0f, 2.0f};

// --- ESTADO POR MOTOR ---
// false = controlando activamente, true = ya llegó y está en reposo
bool holding[3] = {false, false, false};

// Espera primer comando T, antes de activar el control
bool armed = false;

// --- CONTADORES DE ENCODER ---
volatile long encCount[3] = {0, 0, 0};

// Mutex por motor: protege encCount contra race entre isr_A e isr_B del mismo motor
static portMUX_TYPE encMux[3] = {
  portMUX_INITIALIZER_UNLOCKED,
  portMUX_INITIALIZER_UNLOCKED,
  portMUX_INITIALIZER_UNLOCKED
};

// --- PD internos ---
float prev_error[3]     = {0, 0, 0};
unsigned long last_t[3] = {0, 0, 0};
int pwm_out[3]          = {0, 0, 0};

// --- ANTI-ATASCO ---
long enc_prev[3]  = {0, 0, 0};
int  stall_cnt[3] = {0, 0, 0};
bool fault[3]     = {false, false, false};

// --- RATE LIMITER ---
// Rampa de velocidad: si el salto es >30°, avanza 1°/ciclo (10°/100ms a 100 Hz)
float target_ramp[3] = {0.0f, 0.0f, 0.0f};
const float RATE_MAX  = 1.0f;

// --- FILTRO DERIVATIVO ---
// Pasa-bajo en la derivada: reduce picos al cambiar setpoint
float d_prev[3]    = {0.0f, 0.0f, 0.0f};
const float D_ALPHA = 0.7f;

// --- MIN_PWM Y KICKSTART INDEPENDIENTES POR MOTOR ---
// Cada articulación tiene fricción estática diferente:
//   M1 (base,    reducción alta): fricción muy alta → valores mayores
//   M2 (hombro,  reducción media): fricción media
//   M3 (codo,    menor carga):     fricción baja
const int MIN_PWM_CERCA[3] = {100,  75, 60};  // error < 3×deadband (6°)
const int MIN_PWM_LEJOS[3] = {130, 100, 80};  // error ≥ 6°
const int KICK_PWM[3]      = {180, 140, 120}; // PWM de arranque por motor
const int KICK_MS[3]       = {120,  80,  80}; // duración del kick (ms)
int kick_ms[3] = {0, 0, 0};                   // contador regresivo (estado)

// ---------------------------------------------------------------
//  ISRs — Quadratura completa (CHANGE en A y B)
//  portENTER/EXIT_CRITICAL_ISR garantiza atomicidad del += en Xtensa
// ---------------------------------------------------------------
void IRAM_ATTR isr_M1_A() {
  portENTER_CRITICAL_ISR(&encMux[0]);
  encCount[0] += (digitalRead(M1_ENCA) == digitalRead(M1_ENCB)) ? 1 : -1;
  portEXIT_CRITICAL_ISR(&encMux[0]);
}
void IRAM_ATTR isr_M1_B() {
  portENTER_CRITICAL_ISR(&encMux[0]);
  encCount[0] += (digitalRead(M1_ENCA) != digitalRead(M1_ENCB)) ? 1 : -1;
  portEXIT_CRITICAL_ISR(&encMux[0]);
}
void IRAM_ATTR isr_M2_A() {
  portENTER_CRITICAL_ISR(&encMux[1]);
  encCount[1] += (digitalRead(M2_ENCA) == digitalRead(M2_ENCB)) ? 1 : -1;
  portEXIT_CRITICAL_ISR(&encMux[1]);
}
void IRAM_ATTR isr_M2_B() {
  portENTER_CRITICAL_ISR(&encMux[1]);
  encCount[1] += (digitalRead(M2_ENCA) != digitalRead(M2_ENCB)) ? 1 : -1;
  portEXIT_CRITICAL_ISR(&encMux[1]);
}
void IRAM_ATTR isr_M3_A() {
  portENTER_CRITICAL_ISR(&encMux[2]);
  encCount[2] += (digitalRead(M3_ENCA) == digitalRead(M3_ENCB)) ? 1 : -1;
  portEXIT_CRITICAL_ISR(&encMux[2]);
}
void IRAM_ATTR isr_M3_B() {
  portENTER_CRITICAL_ISR(&encMux[2]);
  encCount[2] += (digitalRead(M3_ENCA) != digitalRead(M3_ENCB)) ? 1 : -1;
  portEXIT_CRITICAL_ISR(&encMux[2]);
}

// ---------------------------------------------------------------
//  Prototipos
// ---------------------------------------------------------------
void controlMotor(int idx, int in1, int in2, int ena);
void apagarMotor(int in1, int in2, int ena);
void procesarSerial();

// ---------------------------------------------------------------
//  SETUP
// ---------------------------------------------------------------
void setup() {
  // Apagar motores ANTES que cualquier otra cosa para neutralizar
  // el estado de los pines de strapping durante el boot (GPIO15 arranca HIGH)
  pinMode(M1_IN1, OUTPUT); digitalWrite(M1_IN1, LOW);
  pinMode(M1_IN2, OUTPUT); digitalWrite(M1_IN2, LOW);
  pinMode(M1_ENA, OUTPUT); analogWrite(M1_ENA, 255);
  pinMode(M2_IN1, OUTPUT); digitalWrite(M2_IN1, LOW);
  pinMode(M2_IN2, OUTPUT); digitalWrite(M2_IN2, LOW);
  pinMode(M2_ENA, OUTPUT); analogWrite(M2_ENA, 255);
  pinMode(M3_IN1, OUTPUT); digitalWrite(M3_IN1, LOW);
  pinMode(M3_IN2, OUTPUT); digitalWrite(M3_IN2, LOW);
  pinMode(M3_ENA, OUTPUT); analogWrite(M3_ENA, 255);

  Serial.begin(115200);

  for (int i = 0; i < 3; i++) last_t[i] = millis();

  // Encoders
  pinMode(M1_ENCA, INPUT_PULLUP); pinMode(M1_ENCB, INPUT_PULLUP);
  pinMode(M2_ENCA, INPUT_PULLUP); pinMode(M2_ENCB, INPUT_PULLUP);
  pinMode(M3_ENCA, INPUT_PULLUP); pinMode(M3_ENCB, INPUT_PULLUP);

  attachInterrupt(digitalPinToInterrupt(M1_ENCA), isr_M1_A, CHANGE);
  attachInterrupt(digitalPinToInterrupt(M1_ENCB), isr_M1_B, CHANGE);
  attachInterrupt(digitalPinToInterrupt(M2_ENCA), isr_M2_A, CHANGE);
  attachInterrupt(digitalPinToInterrupt(M2_ENCB), isr_M2_B, CHANGE);
  attachInterrupt(digitalPinToInterrupt(M3_ENCA), isr_M3_A, CHANGE);
  attachInterrupt(digitalPinToInterrupt(M3_ENCB), isr_M3_B, CHANGE);

  Serial.println("READY");
}

// ---------------------------------------------------------------
//  LOOP
// ---------------------------------------------------------------
void loop() {
  procesarSerial();

  // Leer encoders de forma atómica
  noInterrupts();
  long c0 = encCount[0], c1 = encCount[1], c2 = encCount[2];
  interrupts();

  current_q[0] = (c0 / PULSOS_POR_VUELTA) * 360.0f;
  current_q[1] = (c1 / PULSOS_POR_VUELTA) * 360.0f;
  current_q[2] = (c2 / PULSOS_POR_VUELTA) * 360.0f;

  // Rate limiter: avanza target_ramp hacia target_q en pasos de RATE_MAX
  for (int i = 0; i < 3; i++) {
    float diff = target_q[i] - target_ramp[i];
    if (fabsf(diff) > RATE_MAX) {
      target_ramp[i] += (diff > 0) ? RATE_MAX : -RATE_MAX;
      if (armed) holding[i] = false;  // mantener activo mientras rampa avanza
    } else {
      target_ramp[i] = target_q[i];
    }
  }

  if (armed) {
    controlMotor(0, M1_IN1, M1_IN2, M1_ENA);
    controlMotor(1, M2_IN1, M2_IN2, M2_ENA);
    controlMotor(2, M3_IN1, M3_IN2, M3_ENA);
  }

  // Telemetría: D,q1,q2,q3,e1,e2,e3,pwm1,pwm2,pwm3
  float e[3];
  for (int i = 0; i < 3; i++) e[i] = target_q[i] - current_q[i];

  Serial.print("D,");
  Serial.print(current_q[0], 2); Serial.print(",");
  Serial.print(current_q[1], 2); Serial.print(",");
  Serial.print(current_q[2], 2); Serial.print(",");
  Serial.print(e[0], 3);         Serial.print(",");
  Serial.print(e[1], 3);         Serial.print(",");
  Serial.print(e[2], 3);         Serial.print(",");
  Serial.print(pwm_out[0]);      Serial.print(",");
  Serial.print(pwm_out[1]);      Serial.print(",");
  Serial.println(pwm_out[2]);

  delay(10);
}

// ---------------------------------------------------------------
//  Control PD con estado HOLDING
//
//  Estados:
//    holding=false → aplica PD normalmente
//    holding=true  → motor en reposo total (no escribe pines),
//                    solo monitorea si el error crece de nuevo
//                    (p.ej. perturbación externa) para reactivar.
// ---------------------------------------------------------------
void controlMotor(int idx, int in1, int in2, int ena) {
  // Motor en FAULT — apagado hasta ZERO o DISARM
  if (fault[idx]) {
    apagarMotor(in1, in2, ena);
    pwm_out[idx] = 0;
    return;
  }

  float error = target_ramp[idx] - current_q[idx];

  if (holding[idx]) {
    // Reactivar solo si el error supera 1.5× deadband (más sensible que 2×
    // para reducir el salto de corriente al reengancharse)
    if (fabsf(error) > deadband[idx] * 1.5f) {
      holding[idx]    = false;
      kick_ms[idx]    = KICK_MS[idx];  // kickstart por motor para romper fricción
      prev_error[idx] = error;     // evitar spike derivativo al reactivar
      last_t[idx]     = millis();
    } else {
      pwm_out[idx] = 0;
      return;
    }
  }

  // Dentro de zona muerta → freno y marcar holding
  if (fabsf(error) < deadband[idx]) {
    apagarMotor(in1, in2, ena);
    pwm_out[idx]    = 0;
    prev_error[idx] = error;
    last_t[idx]     = millis();
    holding[idx]    = true;
    return;
  }

  // Control PD activo
  unsigned long now = millis();
  float dt = (now - last_t[idx]) / 1000.0f;
  if (dt <= 0.0f) dt = 0.01f;
  if (dt > 0.1f)  dt = 0.1f;   // clamp: evita spike si el loop se pausa

  float d_raw      = (error - prev_error[idx]) / dt;
  d_prev[idx]      = D_ALPHA * d_prev[idx] + (1.0f - D_ALPHA) * d_raw;
  int power = (int)(fabsf(error * Kp[idx] + d_prev[idx] * Kd[idx]));
  if (power > 255) power = 255;
  // PWM mínimo independiente por motor (fricción estática diferente por articulación).
  int min_pwm = (fabsf(error) < deadband[idx] * 3.0f)
                ? MIN_PWM_CERCA[idx] : MIN_PWM_LEJOS[idx];
  if (power < min_pwm) power = min_pwm;

  // Kickstart: durante los primeros KICK_MS[idx] ms aplica al menos KICK_PWM[idx].
  // Nota: KICK_PWM[0]=180 > umbral anti-atasco (150), pero el kick dura solo
  // 120 ms (12 ciclos), insuficiente para alcanzar los 50 ciclos de FAULT.
  if (kick_ms[idx] > 0) {
    if (power < KICK_PWM[idx]) power = KICK_PWM[idx];
    kick_ms[idx] -= (int)(dt * 1000.0f);
    if (kick_ms[idx] < 0) kick_ms[idx] = 0;
  }

  pwm_out[idx]    = power;
  prev_error[idx] = error;
  last_t[idx]     = now;

  // Detección de atasco: PWM alto y encoder sin avanzar durante 500 ms (50 ciclos)
  noInterrupts(); long c_now = encCount[idx]; interrupts();
  if (power > 150 && labs(c_now - enc_prev[idx]) < 5) {
    if (++stall_cnt[idx] >= 50) {
      fault[idx] = true;
      apagarMotor(in1, in2, ena);
      pwm_out[idx] = 0;
      char msg[12]; snprintf(msg, sizeof(msg), "FAULT:M%d", idx + 1);
      Serial.println(msg);
      enc_prev[idx] = c_now;
      return;
    }
  } else {
    stall_cnt[idx] = 0;
  }
  enc_prev[idx] = c_now;

  // Dirección: XOR con INVERTIDO[] para corregir cableado físico de M2 y M3
  bool dir_pos = (error > 0) ^ INVERTIDO[idx];
  if (dir_pos) {
    digitalWrite(in1, HIGH); digitalWrite(in2, LOW);
  } else {
    digitalWrite(in1, LOW);  digitalWrite(in2, HIGH);
  }
  analogWrite(ena, power);
}

// Freno activo L298N: IN1=IN2=LOW + ENA=255 → brake-to-GND
// Reduce overshoot significativamente vs coast (ENA=0)
void apagarMotor(int in1, int in2, int ena) {
  digitalWrite(in1, LOW);
  digitalWrite(in2, LOW);
  analogWrite(ena, 255);
}

// ---------------------------------------------------------------
//  Parser serial
//  T,q1,q2,q3     → nuevo target (resetea holding)
//  K1/K2/K3,Kp,Kd → ganancias
//  DB,d1,d2,d3    → deadband
//  ZERO           → reset encoders
// ---------------------------------------------------------------
void procesarSerial() {
  while (Serial.available() > 0) {
    String data = Serial.readStringUntil('\n');
    data.trim();
    if (data.length() == 0) continue;

    if (data.startsWith("T,")) {
      int c1 = data.indexOf(',', 2);
      int c2 = data.indexOf(',', c1 + 1);
      if (c1 > 0 && c2 > 0) {
        target_q[0] = data.substring(2,    c1).toFloat();
        target_q[1] = data.substring(c1+1, c2).toFloat();
        target_q[2] = data.substring(c2+1).toFloat();
        // Clampear a límites por software
        for (int i = 0; i < 3; i++) {
          if (target_q[i] < LIMIT_NEG[i]) {
            target_q[i] = LIMIT_NEG[i];
            char lm[12]; snprintf(lm, sizeof(lm), "LIMIT:M%d", i + 1);
            Serial.println(lm);
          } else if (target_q[i] > LIMIT_POS[i]) {
            target_q[i] = LIMIT_POS[i];
            char lm[12]; snprintf(lm, sizeof(lm), "LIMIT:M%d", i + 1);
            Serial.println(lm);
          }
        }
        // Rate limiter: saltos >30° arrancan desde posición actual
        for (int i = 0; i < 3; i++) {
          if (fabsf(target_q[i] - current_q[i]) > 30.0f) {
            target_ramp[i] = current_q[i];
          } else {
            target_ramp[i] = target_q[i];
          }
          d_prev[i] = 0.0f;
        }
        // Nuevo target → salir de holding, resetear contadores y kickstart
        for (int i = 0; i < 3; i++) stall_cnt[i] = 0;
        for (int i = 0; i < 3; i++) kick_ms[i] = KICK_MS[i];  // kickstart por motor
        holding[0] = holding[1] = holding[2] = false;
        armed = true;
      }

    } else if (data.startsWith("K") && data.length() > 3 && data.charAt(2) == ',') {
      int idx = data.charAt(1) - '1';
      if (idx >= 0 && idx < 3) {
        int c1 = data.indexOf(',', 3);
        if (c1 > 0) {
          Kp[idx] = data.substring(3, c1).toFloat();
          Kd[idx] = data.substring(c1 + 1).toFloat();
        }
      }

    } else if (data.startsWith("DB,")) {
      int c1 = data.indexOf(',', 3);
      int c2 = data.indexOf(',', c1 + 1);
      if (c1 > 0 && c2 > 0) {
        deadband[0] = data.substring(3,    c1).toFloat();
        deadband[1] = data.substring(c1+1, c2).toFloat();
        deadband[2] = data.substring(c2+1).toFloat();
      }

    } else if (data.equals("ZERO")) {
      noInterrupts();
      encCount[0] = encCount[1] = encCount[2] = 0;
      interrupts();
      target_q[0] = target_q[1] = target_q[2] = 0.0f;
      for (int i = 0; i < 3; i++) { target_ramp[i] = 0.0f; d_prev[i] = 0.0f; kick_ms[i] = 0; }
      holding[0]  = holding[1]  = holding[2]  = true;
      for (int i = 0; i < 3; i++) { fault[i] = false; stall_cnt[i] = 0; }
      armed = false;
      apagarMotor(M1_IN1, M1_IN2, M1_ENA);
      apagarMotor(M2_IN1, M2_IN2, M2_ENA);
      apagarMotor(M3_IN1, M3_IN2, M3_ENA);
      Serial.println("ZEROED");

    } else if (data.equals("DISARM")) {
      armed = false;
      for (int i = 0; i < 3; i++) { fault[i] = false; stall_cnt[i] = 0; kick_ms[i] = 0; }
      apagarMotor(M1_IN1, M1_IN2, M1_ENA);
      apagarMotor(M2_IN1, M2_IN2, M2_ENA);
      apagarMotor(M3_IN1, M3_IN2, M3_ENA);
      Serial.println("DISARMED");

    } else if (data.equals("FREE")) {
      // Costa: ENA=0 — driver deshabilitado, motor gira libre (sin freno)
      armed = false;
      digitalWrite(M1_IN1, LOW); digitalWrite(M1_IN2, LOW); analogWrite(M1_ENA, 0);
      digitalWrite(M2_IN1, LOW); digitalWrite(M2_IN2, LOW); analogWrite(M2_ENA, 0);
      digitalWrite(M3_IN1, LOW); digitalWrite(M3_IN2, LOW); analogWrite(M3_ENA, 0);
      Serial.println("FREE");
    }
  }
}

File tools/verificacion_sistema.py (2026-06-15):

#!/usr/bin/env python3
"""
verificacion_sistema.py — Diagnóstico completo del robot 3-DOF sin MATLAB.

Uso:
    python3 tools/verificacion_sistema.py /dev/ttyUSB0
    python3 tools/verificacion_sistema.py /dev/ttyUSB0 --rapido   (solo Pasos 1-2)

Seguridad:
  - FAULT en cualquier motor → DISARM inmediato y abortar.
  - Error > 30° por más de 3 s → DISARM y reportar.
  - Siempre termina con ZERO antes de cerrar.
"""

import serial
import time
import sys
import re
import os
import argparse

# ── Límites físicos por motor ──────────────────────────────────────────────
LIMITS = {1: (-80, 80), 2: (-45, 45), 3: (-45, 45)}
MOTOR_NAMES = {1: 'M1 (Base)', 2: 'M2 (Hombro)', 3: 'M3 (Codo)'}
BAUD = 115200
CMD_TIMEOUT = 0.1   # s entre lecturas del puerto
TRAMA_TIMEOUT = 5.0 # s esperando una trama válida

# Colores ANSI
GREEN  = '\033[92m'
YELLOW = '\033[93m'
RED    = '\033[91m'
CYAN   = '\033[96m'
BOLD   = '\033[1m'
RESET  = '\033[0m'

def color(texto, c): return c + texto + RESET

def titulo(texto):
    print()
    print(color('═' * 60, CYAN))
    print(color(f'  {texto}', BOLD + CYAN))
    print(color('═' * 60, CYAN))

def subtitulo(texto):
    print(color(f'\n── {texto} ──', YELLOW))

def ok(texto):   print(color('  ✓ ' + texto, GREEN))
def warn(texto): print(color('  ⚠ ' + texto, YELLOW))
def err(texto):  print(color('  ✗ ' + texto, RED))


class Robot:
    def __init__(self, puerto, baud=BAUD):
        self.puerto = puerto
        self.ser = serial.Serial(puerto, baud, timeout=CMD_TIMEOUT)
        time.sleep(0.5)
        self.ser.reset_input_buffer()
        self.faults = []
        self.limits_hit = []

    def close(self):
        try:
            self.ser.close()
        except Exception:
            pass

    def enviar(self, cmd):
        self.ser.write((cmd + '\n').encode())

    def leer_trama(self, timeout=TRAMA_TIMEOUT):
        """Lee hasta obtener una trama D, válida. Devuelve lista de 9 floats o None."""
        t0 = time.time()
        while time.time() - t0 < timeout:
            try:
                linea = self.ser.readline().decode('ascii', errors='ignore').strip()
            except Exception:
                continue
            if linea.startswith('FAULT:'):
                self.faults.append(linea)
                return None
            if linea.startswith('LIMIT:'):
                self.limits_hit.append(linea)
            if linea.startswith('D,'):
                partes = linea[2:].split(',')
                if len(partes) == 9:
                    try:
                        return [float(x) for x in partes]
                    except ValueError:
                        pass
        return None

    def leer_n_tramas(self, n, timeout_total=15.0):
        """Lee n tramas D, válidas. Devuelve lista de listas."""
        tramas = []
        t0 = time.time()
        while len(tramas) < n and time.time() - t0 < timeout_total:
            t = self.leer_trama(timeout=2.0)
            if t is not None:
                tramas.append(t)
        return tramas

    def posicion_actual(self):
        """Devuelve [q1, q2, q3] de la última trama. None si falla."""
        t = self.leer_trama()
        if t:
            return t[0:3]
        return None

    def disarm(self):
        self.enviar('DISARM')
        time.sleep(0.3)

    def zero(self):
        self.enviar('ZERO')
        time.sleep(0.5)

    def esperar_posicion(self, targets, db=5.0, timeout=8.0, max_error=30.0):
        """
        Espera a que todos los motores lleguen a targets ± db.
        Retorna (llegó:bool, tiempo_ms:float, tramas_hist:list).
        Aborta si cualquier motor supera max_error por >3 s o hay FAULT.
        """
        t0 = time.time()
        t_error_alto = {i: None for i in range(3)}
        historia = []
        _printed_limits = set(self.limits_hit)  # no re-reportar LIMIT de pasos anteriores

        while time.time() - t0 < timeout:
            trama = self.leer_trama(timeout=2.0)
            for lm in self.limits_hit:
                if lm not in _printed_limits:
                    print(color(f'  ⚠ {lm} — límite clampeado durante movimiento', YELLOW))
                    _printed_limits.add(lm)
            if trama is None:
                if self.faults:
                    return False, (time.time() - t0) * 1000, historia
                continue

            q = trama[0:3]
            historia.append({'t': time.time() - t0, 'q': q[:], 'e': trama[3:6]})

            # Verificar error excesivo sostenido
            for i in range(3):
                err_abs = abs(q[i] - targets[i])
                if err_abs > max_error:
                    if t_error_alto[i] is None:
                        t_error_alto[i] = time.time()
                    elif time.time() - t_error_alto[i] > 3.0:
                        self.disarm()
                        return False, (time.time() - t0) * 1000, historia
                else:
                    t_error_alto[i] = None

            # Verificar convergencia
            if all(abs(q[i] - targets[i]) < db for i in range(3)):
                return True, (time.time() - t0) * 1000, historia

        return False, timeout * 1000, historia

    def medir_overshoot(self, motor_idx, target, historia):
        """Extrae el overshoot máximo de la historia de una prueba."""
        if not historia:
            return 0.0
        vals = [h['q'][motor_idx] for h in historia]
        if target >= 0:
            pico = max(vals)
            return max(0.0, pico - target)
        else:
            pico = min(vals)
            return max(0.0, target - pico)

    def tiempo_respuesta(self, motor_idx, target, historia, db=5.0):
        """Tiempo en ms hasta que el motor entra en ±db del target por primera vez."""
        for h in historia:
            if abs(h['q'][motor_idx] - target) < db:
                return h['t'] * 1000
        return None  # no llegó


def paso1_comunicacion(robot):
    titulo('PASO 1 — Comunicación básica (20 tramas)')
    print('  Leyendo 20 tramas D,…')

    t0 = time.time()
    tramas = robot.leer_n_tramas(20, timeout_total=15.0)
    elapsed = time.time() - t0

    if len(tramas) < 10:
        err(f'Solo se recibieron {len(tramas)} tramas en {elapsed:.1f}s')
        err('Verifica que el ESP32 está encendido y el firmware cargado.')
        return False

    hz = len(tramas) / elapsed
    ok(f'Recibidas {len(tramas)} tramas en {elapsed:.1f}s ({hz:.1f} Hz)')

    q = tramas[-1][0:3]
    ok(f'Posición actual: M1={q[0]:.1f}°  M2={q[1]:.1f}°  M3={q[2]:.1f}°')

    for t in tramas:
        if len(t) != 9:
            err('Trama con número incorrecto de campos')
            return False
    ok('Formato de telemetría correcto (9 campos por trama)')
    return True
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

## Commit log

2026-04-28 Robot 3-DOF: firmware ESP32, GUI MATLAB y bridge Python
    Firmware de control PD para 3 motores DC con encoders sobre ESP32.
    GUI de MATLAB con cinemática inversa, visualización 3D y telemetría.
    Bridge serial en Python para uso en Linux.
2026-04-28 Añadir platformio.ini para ESP32
2026-04-28 Reducir ángulo de test de motores de 60° a 15°
2026-04-28 Corregir strsplit: usar char(10) en lugar de newline
2026-04-28 No activar motores hasta recibir primer comando T o ZERO
2026-04-28 Añadir DISARM: motores seguros al conectar sin importar estado previo
2026-04-28 ZERO no arma el robot; boton REGISTRAR CERO prominente en GUI
2026-04-28 Log ocupa todo el espacio restante del panel
2026-04-28 Agregar botones de test individual por motor (M1/M2/M3)
2026-04-28 Kp por defecto a 10 en firmware y GUI para robot cargado
2026-05-04 Reporte
    Añadi los codigos de las validaciones numericas hechas en matlab y la implemtacion en ROS
    [3DOFROBOT.SLDASM, 3DOFROBOT.xml, 5mmFlangeCoupler.SLDPRT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]
2026-06-12 Actualizar README con setup completo y agregar requirements.txt
    - Agregar sección de Requisitos con versiones mínimas (MATLAB R2021a, Python 3.8+)
    - Documentar setup para PlatformIO (recomendado) y Arduino IDE 2.x
    - Corregir protocolo serial: comandos reales del firmware (T,/K1,/DB,/ZERO/etc.)
    - Agregar tabla completa de respuestas del ESP32
    - Agregar requirements.txt con pyserial para el bridge Python
2026-06-12 Agregar scripts de setup automático para Linux/macOS y Windows
2026-06-14 Limpiar repo: eliminar proyecto ROS2 y untrackear archivos auto-generados
    - Eliminar Implementacion ROS/ (proyecto ROS2 anterior, proyecto distinto)
    - Eliminar Validaciones numericas/ (scripts de validación movidos)
    - Untrackear .vscode/ (auto-generado por PlatformIO, ya está en .gitignore)
    - Agregar .vscode/ a .gitignore para excluirlo en el futuro
    [3DOFROBOT.xml, 5mmFlangeCoupler_Default_sldprt.STEP, Arm1_Default_sldprt.STEP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]
2026-06-14 Actualizar CLAUDE.md con valores reales del firmware
    - Protocolo serial: reemplazar comandos legacy (SP:/POS:/RST/KP:/KD:) por
    el protocolo actual T,/D,/K1,/DB,/ZERO/DISARM/FREE con referencias a líneas
    - Parámetros de control: Kp=10.0, Kd=0.05, min_pwm=20/35, LOOP_HZ=~100
    (anteriormente documentados como Kp=2.5, Kd=0.08, MIN_PWM=18, HZ=50/20)
    - COUNTS/REV: marcar 1200 (firmware) como pendiente de verificación física
    - Cinemática: agregar θ3_motor y advertencia de workspace sin validar
    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
2026-06-14 Crear BITACORA.md con registro de sesión 2026-06-14
2026-06-14 Crear robot_serial_bridge.py: bridge serial→TCP para evitar lock file en Linux
2026-06-14 Firmware: proteger encCount con portMUX contra race condition en ISRs
    Las ISRs de canal A y B del mismo motor comparten encCount[i].
    La operación += no es atómica en Xtensa si dos ISRs de distinta
    prioridad se anidan. portENTER/EXIT_CRITICAL_ISR garantiza
    exclusión mutua sin deshabilitar todas las interrupciones.
2026-06-14 platformio.ini: agregar monitor_filters para stack traces legibles en crash
2026-06-14 GUI MATLAB: agregar Refresh ports y validación de workspace en IK
    - Botón ⟳ junto al dropdown de puertos: actualiza serialportlist()
    en tiempo real sin necesidad de reiniciar la GUI (útil si el ESP32
    se reconecta mientras MATLAB está abierto)
    - ikRobot(): detecta cuando D_raw sale de [-1,1] y devuelve errMsg
    con distancia real vs límite de alcance en mm
    - moverRobot(): muestra el errMsg de IK en el log con etiqueta [!]
    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
2026-06-14 refactor: reorganizar estructura del proyecto en carpetas por responsabilidad
    firmware/ → robot3dof_firmware.ino + platformio.ini
    matlab/ → RobotController.m
    tools/ → robot_serial_bridge.py, setup.sh, setup.bat
    docs/ → directorio creado (vacío con .gitkeep)
    Compilación verificada: cd firmware && pio run → [SUCCESS]
    README.md, CLAUDE.md y BITACORA.md actualizados con nuevas rutas.
2026-06-14 fix: corregir PULSOS_POR_VUELTA de 1200 a 1960 (verificación física)
    Con 1200 el motor M1 giraba ~220° al pedir 360°.
    Cálculo: JGA25-370 ~7PPR × 4× cuadratura × 70:1 reducción ≈ 1960 counts/rev.
    [robot3dof_firmware.ino]
2026-06-15 feat: agregar script de diagnóstico de movimiento por motor
    tools/diagnostico_movimiento.py:
    - Prueba secuencial M1/M2/M3 con ángulos 5°→80° y negativos
    - Modo seguro: DISARM automático si atasco (PWM>100, error>20° por 2s)
    o si se supera límite físico (M1 ±80°, M2/M3 ±45°)
    - Tabla de resultados: posición real, error, PWM, diagnóstico por prueba
    - Resumen automático: ángulo mínimo funcional, errores, overshoot,
    parámetros recomendados (deadband, Kp, Kd)
    - Detección de puerto serial automática
    [diagnostico_movimiento.py]
2026-06-15 fix: reducir deadband de 5° a 2° para responder a ángulos pequeños
    Valor anterior: 5.0° — causa raíz del problema de ángulos sin respuesta.
    Con 5°, cualquier target ≤5° entraba en holding sin mover el motor.
    Con 2°, el mínimo funcional baja a ~2-3°.
    [robot3dof_firmware.ino]
2026-06-15 feat: protección anti-atasco, límites por software y control por teclado
    firmware/robot3dof_firmware.ino:
    - INVERTIDO[3]={false,true,true}: corrige dirección de M2 y M3
    (verificado físicamente: ambos iban en negativo al pedir positivo)
    - LIMIT_NEG/LIMIT_POS: clampeo de setpoints a ±80°/±45°/±45°,
    responde con LIMIT:M{n} si se supera el límite
    - Anti-atasco: si PWM>150 y encoder quieto (<5 counts) por 500 ms
    → FAULT:M{n}, motor apagado hasta ZERO o DISARM
    - Fault/stall se resetea en ZERO y DISARM; stall_cnt en cada T,
    matlab/RobotController.m:
    - Panel "CONTROL MANUAL (teclado)" visible en la GUI
    A/D=M1 W/S=M2 Q/E=M3 (±5° por tecla)
    Espacio=DISARM R=ZERO
    - fig.Key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
    [robot3dof_firmware.ino]
2026-06-15 docs: actualizar BITACORA con diagnóstico físico y cambios de Fase 3+4
2026-06-15 fix: habilitar scroll en panel izquierdo de la GUI
2026-06-15 fix: corregir visualizacion 3D M2/M3, IK→firmware, FAULT/LIMIT en GUI y buffering CSV
    - leerTelemetria() y leerUnFrame(): negar current_q(2/3) antes de sumar home_q
    para compensar la convencion invertida del encoder en M2 y M3
    - moverRobot(): negar q_fw(2/3) antes de enviar T, al firmware (misma convencion)
    - runSequence(): negar fw_target1/2(2/3) para que esperarPosicion compare correctamente
    - leerTelemetria(): parsear mensajes FAULT: y LIMIT: del firmware y mostrarlos en log
    - leerTelemetria(): acumular CSV en buffer, escribir al disco cada 50 tramas
    (elimina el fopen/fclose por frame a 100 Hz)
2026-06-15 tune: ajustar control PD — Kp=6/Kd=0.08, filtro derivativo, rate limiter
    - Kp: 10→6 (reducir overshoot con errores grandes)
    - Kd: 0.05→0.08 (mayor amortiguación)
    - Filtro pasa-bajo en derivada: d_f = 0.7*d_prev + 0.3*d_raw (α=0.7)
    evita picos derivativos al cambiar setpoint
    - Rate limiter: saltos >30° avanzan en pasos de 1°/ciclo (10°/100ms a 100 Hz)
    arranca desde current_q al recibir T, con salto grande
    mientras la rampa avanza se cancela holding para mantener el motor activo
    - ZERO: resetea target_ramp y d_prev junto con encoders
    [robot3dof_firmware.ino]
2026-06-15 docs: actualizar BITACORA.md con cambios de Fase 2 (PD, visual M2/M3, GUI)
2026-06-15 fix: redisenar panel izquierdo en dos columnas — elimina problema de scroll
    Raiz del problema: uipanel con Scrollable='on' dentro de uigridlayout
    en MATLAB/Linux no propaga el overflow al scroll bar — el grid layout
    toma control del tamaño del panel y clipa el contenido sin desplazarlo.
    Solución: dividir el panel izquierdo (390px) en dos columnas via
    uigridlayout [1,2] sin scroll:
    - Columna L (16 filas): DESTINO · SECUENCIA · GANANCIAS PD · ZONA MUERTA
    contenido ~504px — cabe en los ~968px disponibles
    - Columna R (20 filas): CONTROL MANUAL · TEST MOTORES · CONEXIÓN ·
    POSICIÓN CERO · CINEMÁTICA DIRECTA · LOG
    contenido ~724px — cabe en los ~968px disponibles
    Todo e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
2026-06-15 feat: agregar tools/verificacion_sistema.py — diagnostico completo sin MATLAB
    Script de 7 pasos que verifica el sistema completo via pyserial:
    - Paso 1: comunicacion serial (20 tramas, frecuencia real, formato)
    - Paso 2: estabilidad de encoders en reposo (deriva y ruido)
    - Paso 3: respuesta por motor (10°/25°/-10°/-25°/0° c/u) con tabla:
    llegada, tiempo de respuesta, error SS, overshoot, estado
    - Paso 4: limites por software (enviar >80°/>45° y verificar LIMIT:Mn)
    - Paso 5: revision estatica del codigo anti-atasco en firmware
    - Paso 6: movimiento combinado 3 motores (T,20,20,20 / T,-20,-20,-20 / zero)
    - Paso 7: semaforo verde/amarillo/rojo con recomendaciones de ajuste PD
    Segurid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
    [verificacion_sistema.py]
2026-06-15 ui: rediseño layout GUI en 3 columnas para mejor legibilidad
    mainGrid pasa de [2,2] con 390px a [2,3] con 280px+280px+1x.
    Columna 1: DESTINO, SECUENCIA, GANANCIAS PD, ZONA MUERTA.
    Columna 2: CONTROL MANUAL, TEST MOTORES, CONEXIÓN, CERO, FK, LOG.
    Columna 3: modelo 3D + gráfica de control.
    Elimina los ~192px/columna del layout anterior que cortaban textos y botones.
    Valores por defecto Kp/Kd actualizados a 6.0/0.08 para coherencia con firmware.
2026-06-15 tune: aumentar min_pwm para vencer fricción gravitacional (20→30, 35→55)
    Con Kp=6, el término proporcional cae a ~31 PWM a 5° del target.
    El min_pwm anterior (20 cerca / 35 lejos) era insuficiente para vencer
    la fricción estática en dirección positiva (contra gravedad), causando
    undershoot sistemático: M1+10°→4.8°, M2+10°→3.5°, M3+10°→7.0°.
    Valores nuevos (30/55) garantizan torque mínimo en ambas direcciones.
2026-06-15 fix: completar verificación de límites software y timeout adaptativo en script
    - paso4: añadir M2- y M3- negativos a la lista de pruebas (6 casos, antes 4)
    - paso3: timeout adaptativo 4s (≤15°) / 8s (>15°) por ángulo individual
    - paso3: retorno a cero más estricto db=2° (antes db=5°) entre pruebas
    - paso4: reemplazar sleep(1.5) por esperar_posicion(db=3°, timeout=4s)
    - esperar_posicion: log inmediato de mensajes LIMIT: recibidos durante movimiento
    [verificacion_sistema.py]
2026-06-15 tune: aumentar MIN_PWM y agregar kickstart anti-fricción
    Motores JGA25-370 con reducción 70:1 tienen fricción estática alta
    que impedía arrancar desde reposo con parámetros anteriores.
    - min_pwm: 30/55 → 60/80 (zona cercana/lejana al target)
    - Kickstart: PWM_KICK=120 durante 80ms al salir de HOLDING o T nuevo
    El kick actúa en el handler T y en la reactivación por perturbación.
    Se resetea en ZERO, DISARM y T. Queda bajo el umbral de anti-atasco (150).
    - Kp: 6.0 → 8.0 (más fuerza proporcional en rango medio)
    - Kd: 0.08 → 0.10 (más amortiguación para compensar Kp mayor)
    Compilación limpia: 21.6% Flash, 6.8% RAM.
    [robot3dof_firmware.ino]
2026-06-15 tune: MIN_PWM y kickstart independientes por motor
    Medición física confirmó fricción estática diferente por articulación.
    M1 necesita ~75° de setpoint para arrancar; M3 funciona desde ángulos pequeños.
    Firmware — arrays por motor reemplazan escalares globales:
    MIN_PWM_CERCA: M1=100 M2=75 M3=60 (error < 6°)
    MIN_PWM_LEJOS: M1=130 M2=100 M3=80 (error ≥ 6°)
    KICK_PWM: M1=180 M2=140 M3=120 (boost al arrancar)
    KICK_MS: M1=120ms M2=80ms M3=80ms
    KICK_PWM[0]=180 supera umbral anti-atasco (150) pero el kick dura
    120ms (~12 ciclos), insuficiente para disparar FAULT (requiere 50).
    Script — fix falsos LIMIT en paso 6:
    _printed_limits = set(self.limits_h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
    [robot3dof_firmware.ino, verificacion_sistema.py]
